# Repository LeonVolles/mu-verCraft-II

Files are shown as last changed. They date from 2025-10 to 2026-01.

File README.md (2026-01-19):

# µ-verCraft II

In this project we develloped a micro autonomous hovercraft with WiFi control, PID-stabilized yaw control, and autonomous navigation capabilities.

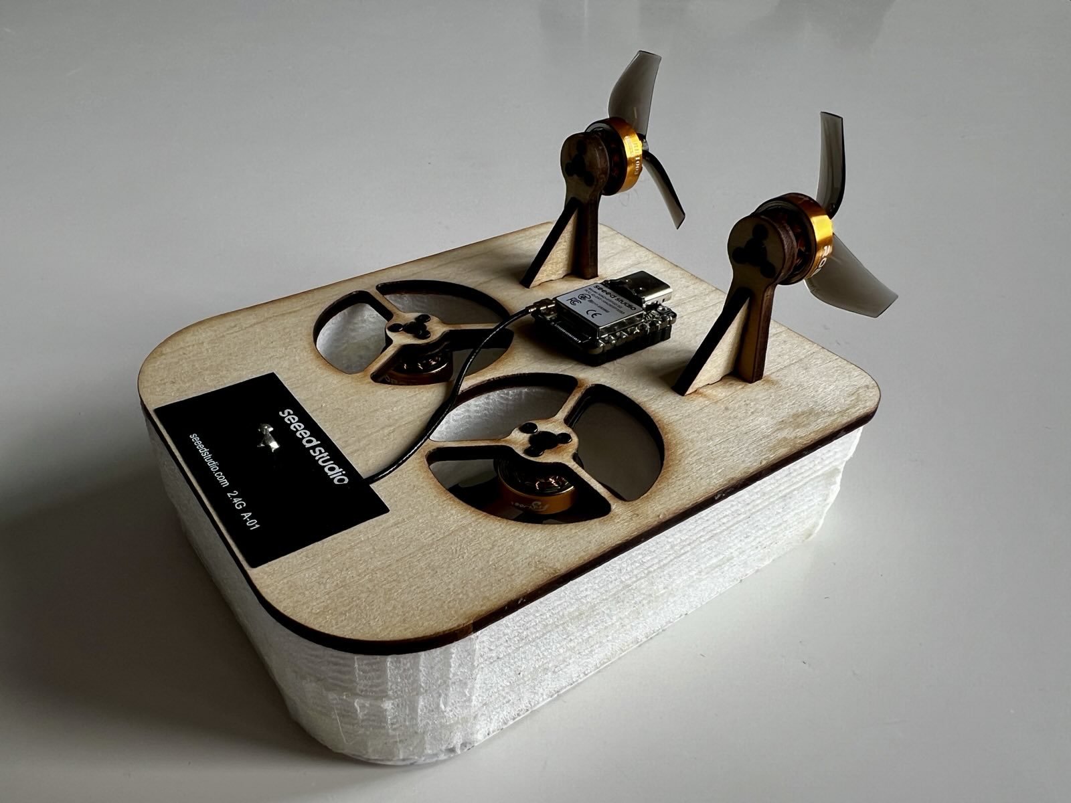
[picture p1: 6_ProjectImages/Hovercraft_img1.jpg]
µ-verCraft II hovercraft


## Overview

µ-verCraft II is an ESP32-S3-based hovercraft designed to navigate autonomously along a predefined track in the ENSMM hall. The system uses IR sensors for line detection, a 10-DOF IMU for orientation, and implements real-time control using FreeRTOS.

## Features

- **WiFi-based remote control** via web interface (no app required)
- **PID yaw-rate stabilization** using complementary filter and magnetometer
- **Autonomous navigation mode** with IR line detection and position correction
- **Real-time telemetry** (battery voltage, current, capacity estimation)
- **DShot ESC protocol** for brushless motor control

## Hardware

- ESP32-S3 microcontroller
- 10-DOF IMU (ADXL345, ITG3205, QMC5883, BMP280)
- 4x brushless motors with ESCs
- IR sensors for line tracking
- LiPo battery monitoring system

## CAD

- The CAD was created in Creo10 and is provided

## Getting Started

1. Clone the repository
2. Open in VS Code with PlatformIO extension
3. Calibrate magnetometer using provided protocol
4. Connect to WiFi AP and access web interface for control

## Project Structure

- `src/main.cpp` - Main entry point with FreeRTOS task setup
- `src/hovercraft_variables.*` - Global configuration and pin definitions
- Motor control, IMU, PID, battery monitoring, and WiFi modules

---

**ENSMM/Supmicrotech - Project PIST 2025/26 - Leon VOLLES & Luis GÖBES**

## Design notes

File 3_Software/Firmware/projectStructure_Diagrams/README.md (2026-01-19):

# Project Structure Diagrams

This folder contains scripts that generate architecture/project diagrams.

## Icon legend (local)

The generators use custom icons from `projectStructure_Diagrams/icons/`:
- `Hovercraft_variables.png` = configuration blocks
- `task.png` = RTOS tasks
- `data.png` = data/state/queues/globals
- `function.jpg` = functions/logic blocks
- `motor.png` = motors / propulsion

When none of these fit, the generators use `cpp.png` as a generic fallback icon.

## High-level code-structure diagrams

Generator:
- `generate_code_structure_high_level.py`

Outputs:
- `high_level_setup.png` (only: `main` creates RTOS tasks)
- `high_level_manual_piloting.png` (Web-App -> yaw PID + 10DOF/comp filter -> mixer -> motor ctrl -> DSHOT -> motors)

## Motor stack overview

Generates a first architecture overview for:
- `lib/motor_mixer`
- `lib/motor_ctrl`

### Prerequisites (Windows)

1. Python package:
   - `pip install diagrams`
2. Graphviz (required by `diagrams`):
   - `winget install Graphviz.Graphviz`
   - or `choco install graphviz`

Make sure the Graphviz `dot` executable is available on your `PATH` (open a new terminal after installing).

### Generate

From the firmware root:

```powershell
python .\projectStructure_Diagrams\generate_motor_architecture.py
```

Output:
- `projectStructure_Diagrams/motor_architecture.png`

## Manual mode overview (growing)

Generates a conceptual diagram for the current manual-mode chain:

### Generate

From the firmware root:

```powershell
python .\projectStructure_Diagrams\generate_manual_mode_architecture.py
```

Output:

This script also generates clearly labeled sub-diagrams (to keep the overview readable):

## Autonomous mode (M-Mode) diagrams

Generates diagrams for autonomous mode (the website “M” button), centered around:
- `lib/autonomous_sequence`

### Generate

From the firmware root:

```powershell
python .\projectStructure_Diagrams\generate_autonomous_mode_architecture.py
```

Output:
- `projectStructure_Diagrams/autonomous_mode_architecture.png`
- `projectStructure_Diagrams/autonomous_mode_sequence_core.png`

### Optional: custom output directory

```powershell
python .\projectStructure_Diagrams\generate_motor_architecture.py .\projectStructure_Diagrams
```

Or via env var:

```powershell
$env:DIAGRAM_OUT_DIR = ".\\projectStructure_Diagrams"
python .\projectStructure_Diagrams\generate_motor_architecture.py
```

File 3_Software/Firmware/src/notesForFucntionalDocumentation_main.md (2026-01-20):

<!-- Note, it is intentionnal that the first heading starts as a "level2"/## and not as level1/# and should be kept like this!! -->
## main (application entry point)

### Main idea
This file is the integration point of the whole firmware: it wires together all subsystems (motors, mixer, IMU, WiFi/web control, sensors, battery) and starts the FreeRTOS tasks that make the hovercraft run.

### Where it is used / how it is called
- This is the Arduino entry point compiled by PlatformIO: [src/main.cpp](src/main.cpp).
- `setup()` runs once after boot, then FreeRTOS tasks execute continuously; `loop()` is intentionally unused.

### Project structure: what runs when

#### Boot sequence (high level)
1. **Boot → `setup()`**: initialize peripherals, create the control queue, start WiFi + web control, then create RTOS tasks.
2. **Runtime**: tasks run concurrently on the ESP32’s two cores.
3. **Safety default**: motors start disarmed (`motorsEnabled=false`) and the motor task keeps outputs safe until arming is received.

#### Data flow overview (who talks to whom)
- **Web UI → NetworkPiloting callbacks → control queue**
	- WebSocket messages update `g_latestSetpoints` and immediately publish them using `xQueueOverwrite(g_controlQueue, ...)`.
	- The queue length is 1, so the motor task always consumes the **latest** setpoints.
- **IMU task → shared yaw-rate → motor task**
	- IMU task updates `g_yawRateMeasured_dps` and `g_lastYawRateUpdate_us`.
	- Motor task checks “freshness” (timestamp age) before using yaw-rate for control.
- **Motor task → mixer → motor controller → ESCs**
	- Motor task computes the yaw-rate control command (`diffCmd`) via `PIDController`.
	- `MotorMixer` converts lift/thrust/diff into 4 motor percentages.
	- `MotorCtrl` sends DShot commands to the ESCs.
- **Battery task → shared telemetry → `/debug`**
	- Battery task updates shared telemetry values (voltage/current/mAh).
	- The web UI reads telemetry/state via HTTP polling of `/debug`.

#### Task map (what each task does)
The firmware creates multiple tasks in `setup()` using `xTaskCreatePinnedToCore(...)`.

##### task_wifiManager (core 0)
- Purpose: lightweight periodic diagnostics (heap/stack prints).
- Note: the async server handles network I/O callbacks in its own context; telemetry/state for the UI is served via `/debug`.

##### task_imu (core 1)
- Initializes IMU, then runs a periodic loop at **200 Hz** (`vTaskDelayUntil(..., 5ms)`).
- Reads gyro continuously; reads magnetometer slower (~20 Hz) and updates yaw complementary filter.
- Publishes yaw rate (deg/s) to the shared variables for the control loop.

**Heading sign / offset note:** the heading published to the UI and heading-hold (`g_yawMeasured_deg`) is a **mounting-corrected** magnetometer+gyro estimate. The IMU applies a hardcoded transform `heading_corrected = wrap360(180 - heading_raw)` so the displayed heading has the desired 180° offset and increases in the chosen positive rotation direction.

If you later enable a non-zero heading-controller `Kd`, ensure the yaw-rate signal used for derivative-on-measurement has the **same sign convention** as the heading (positive yaw-rate means heading increasing).

##### task_motorManagement (core 1)
- Runs the main control loop at `global_ControlLoopRate_Hz` using `vTaskDelayUntil`.
- Non-blocking reads of `g_controlQueue` to get the latest setpoints.
- Implements yaw-rate control:
	- Converts steering percent to yaw-rate setpoint using `global_MaxYawRateSetpoint_dps`.
	- If motors are armed and gyro data is fresh: `PIDController.update(...)` → `diffCmd`.
	- Otherwise: PID reset + `diffCmd = 0`.
- Applies safety gates:
	- Always calls `motorCtrl.setMotorsEnabled(mySetPoint.motorsEnabled)`.
	- If disarmed, forces thrust and diff to zero; lift can be “latched” but not applied until arming.
	- If lift is disabled, calls `motorCtrl.applyLiftOff()` and forces mixer lift to 0.

##### task_irSensors (core 1)
- Polls for ISR-completed measurements (`irSensors.hasNewMeasurement()`) and consumes them.
- Currently prints debug values (angle to line, lateral velocity). Intended as a future navigation input.
- Typical polling delay is ~20ms.

##### task_batteryMonitor (core 1)
- Calls `batteryMonitor.update()` and prints voltage/current/mAh.
- Updates shared telemetry state used by `/debug`.

##### task_blink (core 1)
- Simple LED blink for testing.

### Functionalities implemented (project-level)
- **System bring-up**: initialize motor outputs, mixer state, sensor interrupts, battery ADC scaling, WiFi AP, and web control.
- **Real-time scheduling**: run IMU acquisition and control loop periodically with `vTaskDelayUntil`.
- **Command & telemetry plumbing**:
	- WebSocket commands → queue → control loop.
	- Telemetry/state → `/debug` JSON (polled by the web UI).
- **Core separation**: keep network housekeeping on core 0; keep control/sensing on core 1.
- **Safety behaviors**: disarm defaults, lift-off handling, PID reset on stale sensor data.

### Methods / functions overview
This file is mostly glue code and task entry points (not a class).

- `setup()`
	- Initializes serial + LED, motors (`motorCtrl.init(...)`), mixer (`motorMixer.init()`), IR sensors (`irSensors.begin()`), battery monitor (`batteryMonitor.init(...)`).
	- Creates the control queue (`g_controlQueue = xQueueCreate(1, sizeof(ControlSetpoints))`).
	- Starts WiFi AP and registers NetworkPiloting callbacks (lift/thrust/steering/arm).
	- Calls `networkPiloting.begin()` and creates RTOS tasks.

- `loop()`
	- Empty by design (everything runs in tasks).

- Task functions (`task_wifiManager`, `task_imu`, `task_motorManagement`, `task_irSensors`, `task_batteryMonitor`, `task_blink`)
	- Each is an infinite loop; timing is controlled by `vTaskDelay(...)` or `vTaskDelayUntil(...)`.

### Parameters used (configuration & tuning)
Most parameters come from [src/hovercraft_variables.h](src/hovercraft_variables.h) (with definitions in [src/hovercraft_variables.cpp](src/hovercraft_variables.cpp)). Key groups:

- **Motor hardware & safety**: `global_PIN_MOTOR_*`, `global_MotorsReversed*`, `global_AllMotorsScalePercent`.
- **Control loop**: `global_ControlLoopRate_Hz`, `global_MaxYawRateSetpoint_dps`.
- **Yaw-rate PID**: `global_YawRatePid_Kp`, `global_YawRatePid_Ki`, `global_YawRatePid_Kd`, `global_YawRatePid_OutputLimit`, `global_YawRatePid_IntegratorLimit`.
- **IMU filter**: `global_ComplementaryFilter_yawAlpha`.
- **Web control scaling**: `global_WebThrustPresetPercent`.
- **WiFi**: `global_WifiApSsid`, `global_WifiApPassword`.
- **IR sensors**: `global_PIN_IR_SENSOR_*`, `global_IRSensorDistance_a_meters`.
- **Battery monitor**: `global_PIN_BATTERY_*`, `global_BatteryVoltage_VoltageDividerRatio`, `global_BatteryCurrent_VoltageDividerRatio`, `global_BatteryCurrent_SensorScaler_AmpsPerVolt`.

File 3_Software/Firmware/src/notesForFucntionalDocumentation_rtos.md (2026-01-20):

<!-- Note, it is intentionnal that the first heading starts as a "level2"/## and not as level1/# and should be kept like this!! -->
## RTOS (FreeRTOS on ESP32)

### For people that are new to multi-threading
An RTOS lets you split one big `loop()` into multiple independent “tasks” that run *as if* they were in parallel. The RTOS decides which task runs when, so timing-critical work (e.g. control loops) can keep a stable update rate even while other work (e.g. networking) is happening.

### Main idea
This firmware uses FreeRTOS to run multiple subsystems concurrently (IMU, control loop, sensors, diagnostics) with explicit timing and priorities.

Networking is implemented using an async web stack (AsyncTCP/ESPAsyncWebServer). Its callbacks run in their own context, so the project does not need a dedicated “networking loop task” for basic operation.

### What an RTOS is (and why we use it)
FreeRTOS is a small real-time operating system used on microcontrollers. “Real-time” here means we care about predictable timing: a task can run periodically (e.g. every 5ms) and the scheduler helps keep that periodic behavior even when other tasks are active.

Official FreeRTOS website: https://www.freertos.org/

### Two cores on the ESP32 (what that means)
Many ESP32 chips have two CPU cores. In practice that means the RTOS can run one task on core 0 while another task runs on core 1 at the same time.

In this firmware we *pin* some tasks to a specific core using `xTaskCreatePinnedToCore(...)`:
- **Core pinning** is mainly used to isolate “noisy” workloads (like network/web housekeeping) from timing-sensitive workloads (like sensor reading / control loops).
- Pinning does not magically make code thread-safe: any data shared between tasks still needs safe handoff (queues, atomic variables, etc.).

### Scheduling (very short reminder)
The scheduler is the RTOS component that decides which task runs next based on priority and “readiness”. A task becomes not-ready when it blocks (e.g. delays for some time, waits on a queue), and ready again when that wait condition is satisfied.

Common timing patterns you’ll see in this firmware:
- `vTaskDelay(...)`: simple “sleep” for at least a given time.
- `vTaskDelayUntil(...)`: periodic scheduling pattern (tries to keep a constant period, useful for control loops).

### RTOS building blocks used in this project (high level)
- **Tasks:** each subsystem runs in its own task function.
- **Priorities:** tasks can be assigned different priorities so time-critical tasks run first.
- **Queues:** tasks exchange data without sharing raw variables directly (producer/consumer pattern).

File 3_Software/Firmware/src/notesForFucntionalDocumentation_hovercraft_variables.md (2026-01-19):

<!-- Note, it is intentionnal that the first heading starts as a "level2"/## and not as level1/# and should be kept like this!! -->
## hovercraft_variables (global project settings)

### Main idea
This file is the single place to tune the hovercraft: pin assignments, control loop tuning, and user-facing presets are centralized here so you don’t have to hunt through every subsystem.

### Where it is used / how it is called
- Declarations live in [src/hovercraft_variables.h](src/hovercraft_variables.h) and the actual values are defined in [src/hovercraft_variables.cpp](src/hovercraft_variables.cpp).
- Almost every subsystem consumes these values indirectly, but the main wiring is done in [src/main.cpp](src/main.cpp) when objects are constructed and initialized.

### Define all IO-Pins 
These constants define how the ESP32 is wired to the hardware. If the wiring changes, change values here.

- `LED_PIN` (int)
	- Onboard status LED used by the blink test task in [src/main.cpp](src/main.cpp).
	- Default is `LED_BUILTIN`.

- `global_PIN_MOTOR_FL`, `global_PIN_MOTOR_FR`, `global_PIN_MOTOR_BL`, `global_PIN_MOTOR_BR` (gpio_num_t)
	- DShot/ESC signal pins for the 4 motors (Front-Left, Front-Right, Back-Left, Back-Right).
	- Used in `motorCtrl.init(...)` in [src/main.cpp](src/main.cpp).

- `global_PIN_BATTERY_VOLTAGE_MONITOR`, `global_PIN_BATTERY_CURRENT_MONITOR` (gpio_num_t)
	- ADC pins for battery voltage and current sensing.
	- Passed to `batteryMonitor.init(...)` in [src/main.cpp](src/main.cpp).

- `global_PIN_IR_SENSOR_FL`, `global_PIN_IR_SENSOR_FR`, `global_PIN_IR_SENSOR_BM` (gpio_num_t)
	- ADC pins for the 3 IR line sensors (Front-Left, Front-Right, Back-Middle).
	- Sampled via `analogRead(...)` in `task_irSensors` in [src/main.cpp](src/main.cpp) (mapping/order: index0=BM, index1=FL, index2=FR).
	- Passed into the `IRSensors` constructor; `IRSensors::begin()` currently creates the internal sample queue used between the sampling and processing tasks.

- `global_PIN_I2C_SDA`, `global_PIN_I2C_SCL` (gpio_num_t)
	- Intended I2C pin definitions for sensors.
	- Note: the current IMU implementation starts I2C via `Wire.begin((int)SDA_PIN,(int)SCL_PIN)` if the macros `SDA_PIN`/`SCL_PIN` are defined, otherwise it calls `Wire.begin()` defaults (see [lib/imu/src/imu.cpp](lib/imu/src/imu.cpp)). These globals are currently not referenced directly.

### Battery related limits and variables 
These constants configure how ADC readings are converted into real battery voltage/current, plus optional low-voltage thresholds.

- `global_BatteryVoltage_VoltageDividerRatio` (float)
	- Divider ratio used to reconstruct battery voltage from the ADC pin voltage.
	- The battery monitor computes: $V_{batt} = V_{pin} / ratio$ (see [lib/battery_monitor/src/battery_monitor.cpp](lib/battery_monitor/src/battery_monitor.cpp)).
	- For a simple resistor divider, a typical ratio is $ratio = R_{bottom} / (R_{top}+R_{bottom})$.

- `global_BatteryCurrent_VoltageDividerRatio` (float)
	- Scaling factor applied to the measured current-sense pin voltage.
	- The battery monitor computes `sensor_mV = iPin_mV * ratio`.
	- Keep at `1.0` if you have no divider/scaler on the current sense line.

- `global_BatteryCurrent_SensorScaler_AmpsPerVolt` (float)
	- Betaflight-style current scale, **in units of [0.1 mV]/A** (despite the variable name).
	- The battery monitor converts it to mV/A via `mvPerAmp = scale * 0.1` and computes $I(A)=sensor_{mV}/(mV/A)$.
	- Example: `130` means 13 mV/A.

- `global_BatteryVoltageLow_WarningLow` (float, Volts)
	- Intended warning threshold for low battery.
	- Note: currently not enforced automatically; battery voltage is mainly sent as telemetry (see the battery task in [src/main.cpp](src/main.cpp)).

- `global_BatteryVoltageLow_MotorCutoffLow` (float, Volts)
	- Intended hard cutoff threshold where motors should stop.
	- Note: currently not enforced automatically; you can implement a failsafe in the motor task or battery task based on this.

### Motor control variables 
These variables define motor output scaling and direction conventions.

- `global_AllMotorsScalePercent` (float, %)
	- Global power cap applied inside `MotorCtrl` to reduce maximum throttle.
	- Used when `MotorCtrl motorCtrl(global_AllMotorsScalePercent)` is constructed in [src/main.cpp](src/main.cpp).

- `global_NegativeRpmScaleFactor` (float)
	- Reverse-direction compensation factor.
	- Applied only when a motor command is negative, to boost reverse output if reverse thrust is weaker (used in [lib/motor_ctrl/src/motor_ctrl.cpp](lib/motor_ctrl/src/motor_ctrl.cpp)).

- `global_MotorsReversedFL`, `global_MotorsReversedFR`, `global_MotorsReversedBL`, `global_MotorsReversedBR` (bool)
	- Per-motor direction flags.
	- Passed into `motorCtrl.init(...)` in [src/main.cpp](src/main.cpp) so that “positive thrust” matches the physical direction of the mounted propellers.
	- These are non-`const` globals, but in the current firmware they are effectively “startup configuration”.

### Web piloting / UI presets 
These values define what the web UI offers (presets) and how user input is interpreted.

- `global_WebLiftPresetPercent_Array[]` (float array, %)
	- List of lift presets shown/cycled in the web UI.
	- Used by the web UI generation logic in [lib/network_piloting/src/network_piloting.cpp](lib/network_piloting/src/network_piloting.cpp).

- `global_WebLiftPresetPercent_Array_len` (size_t)
	- Length of the lift preset array.
	- Used to bound preset iteration in [lib/network_piloting/src/network_piloting.cpp](lib/network_piloting/src/network_piloting.cpp).

- `global_WebLiftPresetPercent_Array_startIndex` (int)
	- Which preset becomes the first “non-zero” selection after startup (startup selection is always 0).
	- Used by preset cycling logic in [lib/network_piloting/src/network_piloting.cpp](lib/network_piloting/src/network_piloting.cpp).

- `global_WebThrustPresetPercent` (float, %)
	- Scales the maximum thrust command coming from the web UI.
	- Implemented in the thrust callback in [src/main.cpp](src/main.cpp): `scaled = thrustPercent * (preset/100)`.

### Wifi SSID, PW, IP addresses 
These parameters configure the ESP32 SoftAP and the webserver port.

- `global_WifiApSsid` (char[])
	- SSID (network name) for the ESP32 Access Point.
	- Used in `wifiManager.startAccessPoint(...)` in [src/main.cpp](src/main.cpp).

- `global_WifiApPassword` (char[])
	- WPA2 password for the Access Point (must be at least 8 characters).
	- Used in `wifiManager.startAccessPoint(...)` in [src/main.cpp](src/main.cpp).

- `global_WebServerPort` (uint16_t)
	- TCP port for the embedded webserver (typically 80).
	- Used to construct the webserver inside `NetworkPiloting` (see [lib/network_piloting/src/network_piloting.cpp](lib/network_piloting/src/network_piloting.cpp)).

### Gyro/IMU/Complementary filter settings 
These values tune the IMU yaw estimation.

- `global_ComplementaryFilter_yawAlpha` (float, unitless)
	- Complementary filter weight for yaw: higher means “trust gyro more, correct slowly with magnetometer”.
	- Used when constructing the IMU and when configuring the filter in the IMU task in [src/main.cpp](src/main.cpp).
	- Typical range is 0…1.

### Control loop constants 
These define timing of the main control loop.

- `global_ControlLoopRate_Hz` (float, Hz)
	- Target frequency of the motor/control task loop.
	- Used to compute the periodic delay in `task_motorManagement` in [src/main.cpp](src/main.cpp).

### PID controller constants 
Yaw-rate control tuning parameters.

- `global_YawRatePid_Kp`, `global_YawRatePid_Ki`, `global_YawRatePid_Kd` (float)
	- Gains for the yaw-rate PID controller.
	- Used to initialize `yawRatePid` in `task_motorManagement` in [src/main.cpp](src/main.cpp).

- `global_YawRatePid_OutputLimit` (float)
	- Output clamp for the PID command (expected mixer units are roughly -100…100).

- `global_YawRatePid_IntegratorLimit` (float)
	- Integrator clamp (anti-windup) in the same units as the PID output.

- `global_MaxYawRateSetpoint_dps` (float, deg/s)
	- Maps full steering input (±100%) to a yaw-rate setpoint.
	- Used in [src/main.cpp](src/main.cpp) to compute the yaw-rate setpoint from the user steering slider.

- `global_YawCenterSensitivity` (float, deg/s)
	- “Center sensitivity” for the yaw command curve: sets how responsive yaw feels for *small* steering deflections.
	- Interpreted as the approximate slope around stick/slider center (0%).
	- Used in [src/main.cpp](src/main.cpp) to shape the mapping from steering percent to yaw-rate setpoint.

- `global_YawRateExpo` (float, unitless, 0…1)
	- “Expo” shaping for the yaw command curve: higher expo makes the response softer around center and ramps up more strongly towards full deflection.
	- Used together with `global_YawCenterSensitivity` and `global_MaxYawRateSetpoint_dps` to compute the yaw-rate setpoint from the user steering slider.
	- Used in [src/main.cpp](src/main.cpp) in the yaw setpoint mapping.
	- **Visualization tool:** there is a curve visualizer at `3_Software/rates.html` (open it in a browser) to inspect the response curve.

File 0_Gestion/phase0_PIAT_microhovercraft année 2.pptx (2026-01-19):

## Projet micro hovercraft

ENSMM / Option SMR

## Objectif long terme (3-4 ans)

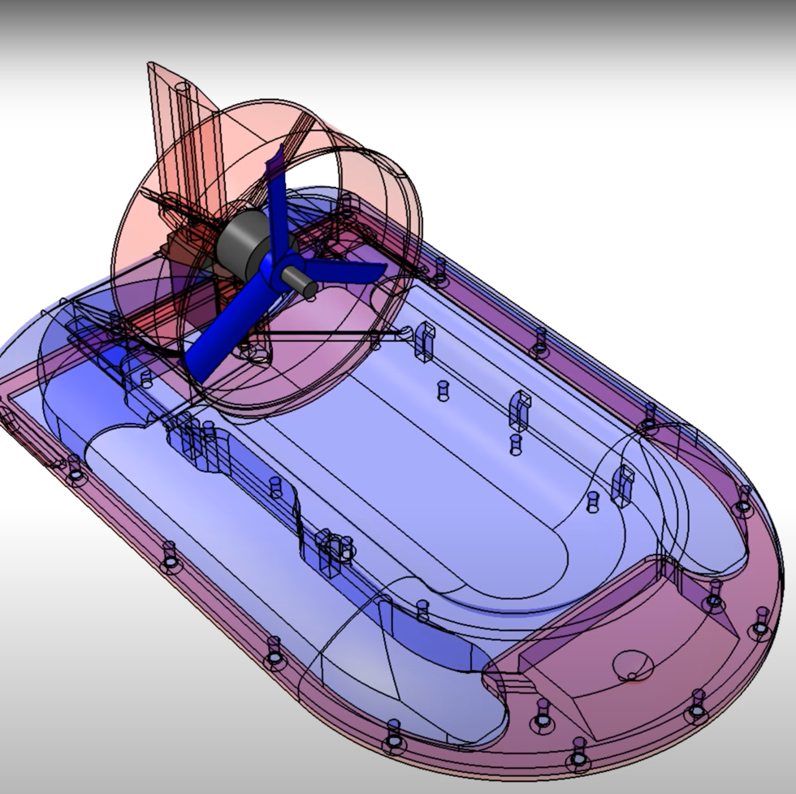
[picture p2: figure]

Course de 2+ micro hovercrafts autonomes dans le hall de l’ensmm

Dimensions caractéristiques des hovercrafts :
entre 10 et 30 cm

## Le circuit

Bandes blanches au sol pour une relocalisation ”alternée” en x et en y

Recalage en y et θ

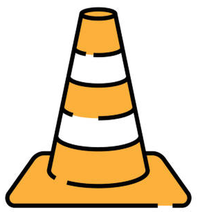
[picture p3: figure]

Recalage en y et θ

Micro hovercrafts qui doivent tourner autour de 2 balises

Recalage en y et θ

y

Recalage en x et θ

x

## Les capteurs embarqués

Extéroceptifs : 2+ capteurs de présence de bande blanche sur le sol
Proprioceptif : centrale inertielle MEMS

La position des bandes blanches étant connue, leur détection par l’hovercraft doit permettre de recaler son angle θ ainsi qu’une des deux composantes x, y qui sont calculés avec la centrale inertielle.
Intérêt : compensation des dérives temporelles induites par l’IMU et calcul de localisations critiques lors du contournement des balises.

## Objectifs année 2 pour une équipe de 2+ étudiants

Du plus prioritaire au moins prioritaire :
1) Conception puis fabrication de la v2 du micro hovercraft sur la base du REX établit par la précédente équipe.
2) Mise au point du module de localisation de l’hovercraft (hardware et softwave) et validation en mode téléopéré (liaison bluetooth)
3) Elaboration d’une première stratégie de commande permettant de faire un tour de circuit en mode autonome.

## Le point de départ (v1)

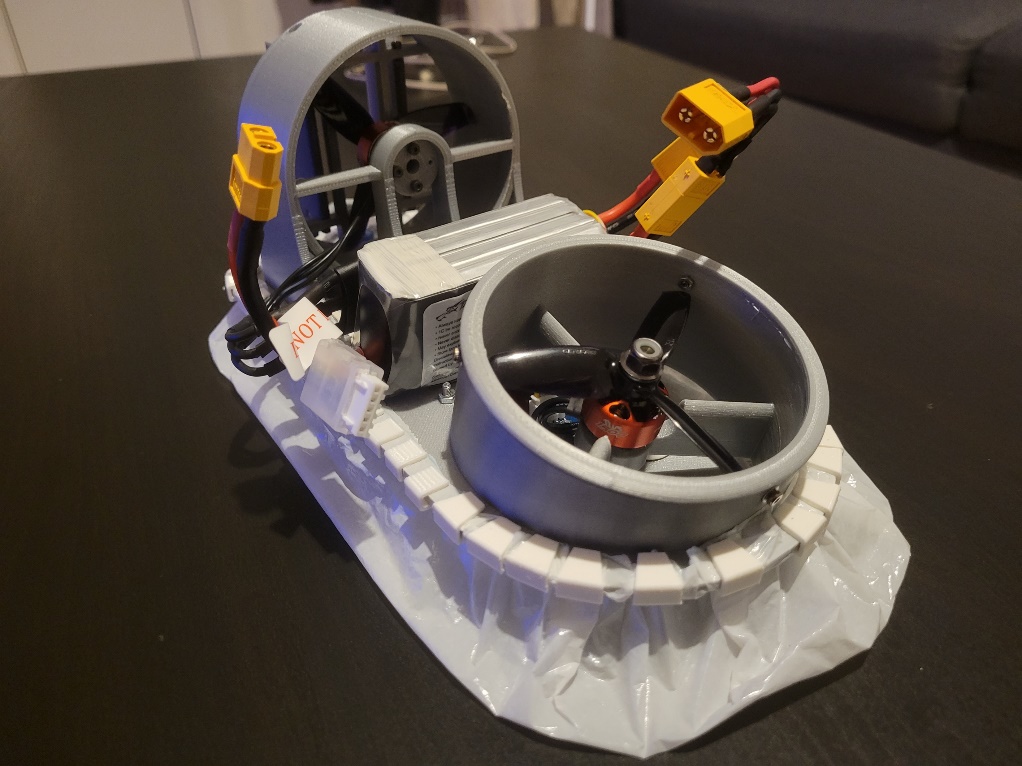
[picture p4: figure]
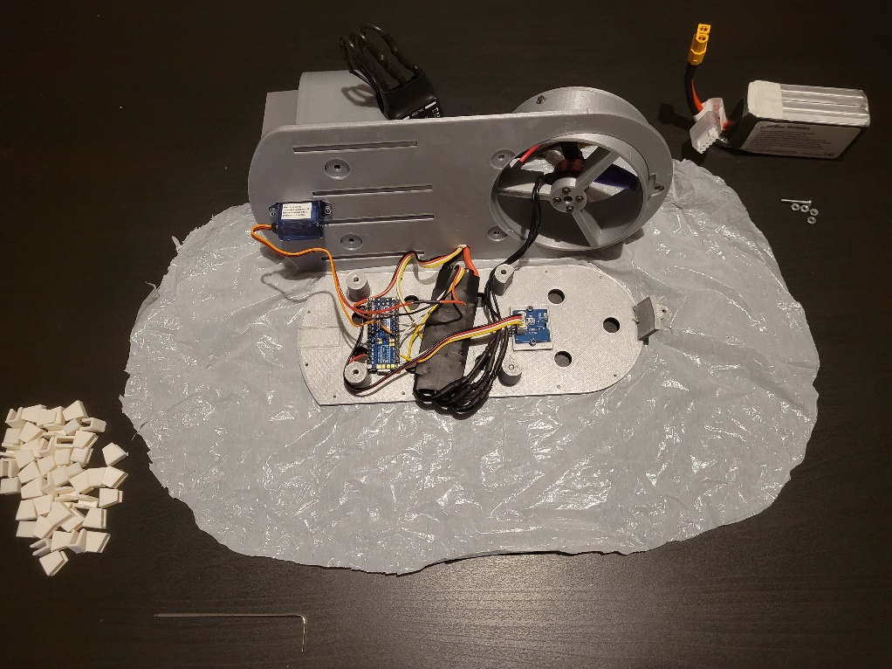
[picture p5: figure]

## Exemples de vidéos sous Youtube

FABRICATION d'un AÉROGLISSEUR TÉLÉCOMMANDÉ (Impression 3D, Assemblage et Test) (https://www.youtube.com/watch?v=NtjMhkQJuBA)
How I 3D Printed a FAST RC Hovercraft (https://www.youtube.com/watch?v=pHdO_BtYl7M)
Mini 3D (https://www.youtube.com/watch?v=mpqYlHTlXtA)Printed (https://www.youtube.com/watch?v=mpqYlHTlXtA) Hovercraft (https://www.youtube.com/watch?v=mpqYlHTlXtA)
Fully 3D printed hovercraft - build guide (https://www.youtube.com/watch?v=PtZ5-50kNHE)
How to make a mini hovercraft at home (https://www.youtube.com/watch?v=1OMSdA4-Gn4)
DIY Mini RC Hovercraft (https://www.youtube.com/watch?v=GS9JsYPLh7w)

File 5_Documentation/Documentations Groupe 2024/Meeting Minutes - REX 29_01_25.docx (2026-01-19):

# Meeting Minutes

Subject | Retour d’expérience pour la passation du projet PIST “Hovercraft”
Date | 29/01/25
Attendees | ENSMM : BARBAUT Christophe, BAUDRI Romuald, PIAT Emmanuel
Author | BAUDRI Romuald

Meeting Objectives/Discussion Points

Mettre en évidence les points à aborder pour le prochain groupe qui prendra ce projet.

- CAO
- Code
- AppInventor
- Liste d’item à acheter
- Liste documentation lien

Topic covered:

- Chargeur de batterie : Entrée 15V DC ; ampérage : 1.5/2.5A ; temps de charge 30 minutes.
- ServoMoteur : Faire attention lors de la manipulation, assez fragile mais fonctionnel.
- Hélices : Penser à des hélices symétrique pour le moteur de poussée
- ESC : Prendre des B-20 (présent sur le même site que précédent, voir dossier Hovercraft (google Sheet) cf.liste achat à la fin)
- Soudure à améliorer, la connexion entre ESC et Moteur.
- ATTENTION POUR LE MOTEUR DANS LE CODE DE CALIBRATION ET DE CONTROL DE NE JAMAIS LANCER UNE PUISSANCE SUPÉRIEUR À 1300µs.
  - Et avec les ESC B-20 le mapping du contrôle sera à refaire et la calibration.
  - TOUJOURS FAIRE ATTENTION A LA SURCHAUFFE DU MOTEUR ET DES CÂBLES
- Batteries : Penser à prendre plus léger, mais pas une priorité seulement à la fin
- Fragilité de la jupe : Matériaux à privilégier : ripstop nylon
- IMU : Pdf d’une thèse sur les IMU (pas simple)
- Vérifier et revoir le code pour le capteur IR, pas sur du fonctionnement.
- Application APP Inventor : https://appinventor.mit.edu/ voir cette outil en ligne (gratuit) uniquement Sur Android (IOS possible mais chiant)
  - Téléchargé sur le github dans le documents : Hovercraft/Code/HovercraftControlApp
  - Télécharger le fichier .aia et l’ouvrir dans l’application.

Lien :

  - https://github.com/RomualdBaudri/Hovercraft
  - https://drive.google.com/drive/folders/1frXN_9IN8mSaBTqvfHWEagb69dfuotS7?usp=sharing

Action Items

- Liste d’item à acheter :
  - PULSAR B-20 Régulateur de vitesse brushless de voiture (https://www.conrad.fr/fr/p/pichler-modellbau-pulsar-b-20-regulateur-de-vitesse-brushless-de-voiture-charge-admissible-max-30-a-3204130.html)
  - Batterie LiPo 650mAh (https://www.conrad.fr/fr/p/tattu-pack-de-batterie-lipo-14-8-v-650-mah-nombre-de-cellules-4-95-c-softcase-xt30-2316799.html) (pas prioritaire)
    - Avec connecteur XT30 (voir avec Mr.Marionnet)
  - Vis CHC M2x10mm, M2x8mm, M2x6mm, M2x4mm avec boulon et rondelle
    - Lien Misumi (https://fr.misumi-ec.com/vona2/mech_screw/M3301000000/) partenaire ENSMM qui a tout type de vis
  - Jeu de tournevis 7 pièces hexagonal (https://www.conrad.fr/fr/p/wiha-jeu-de-tournevis-7-pieces-hexagonal-2481770.html)
  - Servomoteur (https://www.conrad.fr/fr/p/reely-mini-servomoteur-analogique-materiau-entrainement-plastique-systeme-de-connecteur-jr-2148502.html) (On en a cassé un)
- Conseille :
  - revoir avec Pierre ROUX pour la conception des “Rudders” (gouvernaille)
  - Retourner l’hélice de propulsion car montée comme elle est, elle tourne à l'envers…
  - Au niveau de la CAO : Comme pour le capteur IR faire un support pour pour y mettre la carte arduino
  - Prendre du ripstop nylon comme matériau pour la jupe.
  - Lien vers un ensemble de tutorial pour MIT App inventor et l'utilisation du BLE (https://community.appinventor.mit.edu/t/ble-esp32-bluetooth-send-receive-arduino-ide-multitouch/1980/4) (Attention ce n’est pas la même carte donc il faut s’adapter un petit peu)

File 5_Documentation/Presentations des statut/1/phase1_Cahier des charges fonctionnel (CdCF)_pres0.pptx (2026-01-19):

## Projet µ-verCraft

ENSMM / Option SMR

## Préparation

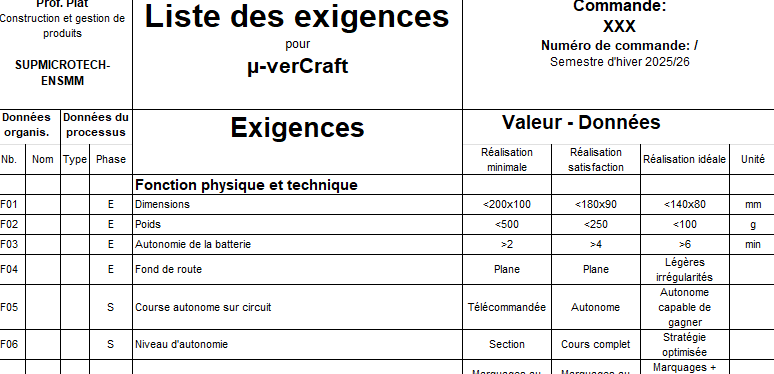
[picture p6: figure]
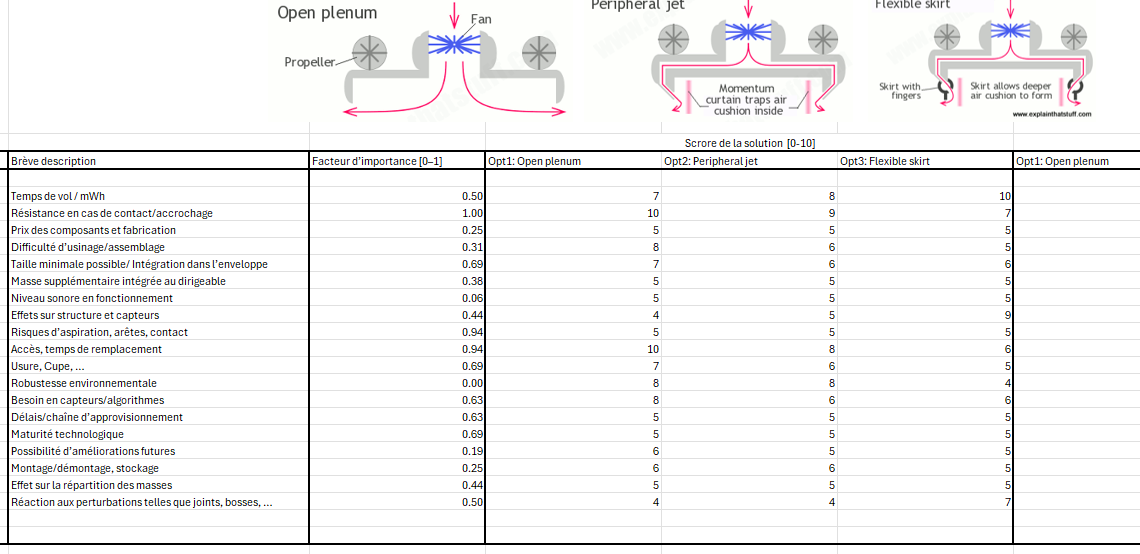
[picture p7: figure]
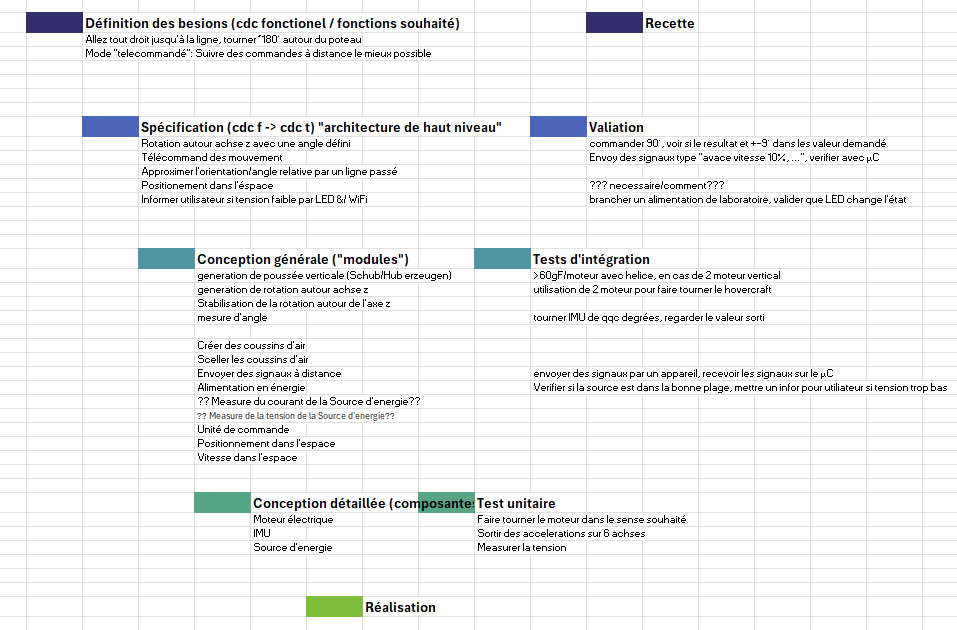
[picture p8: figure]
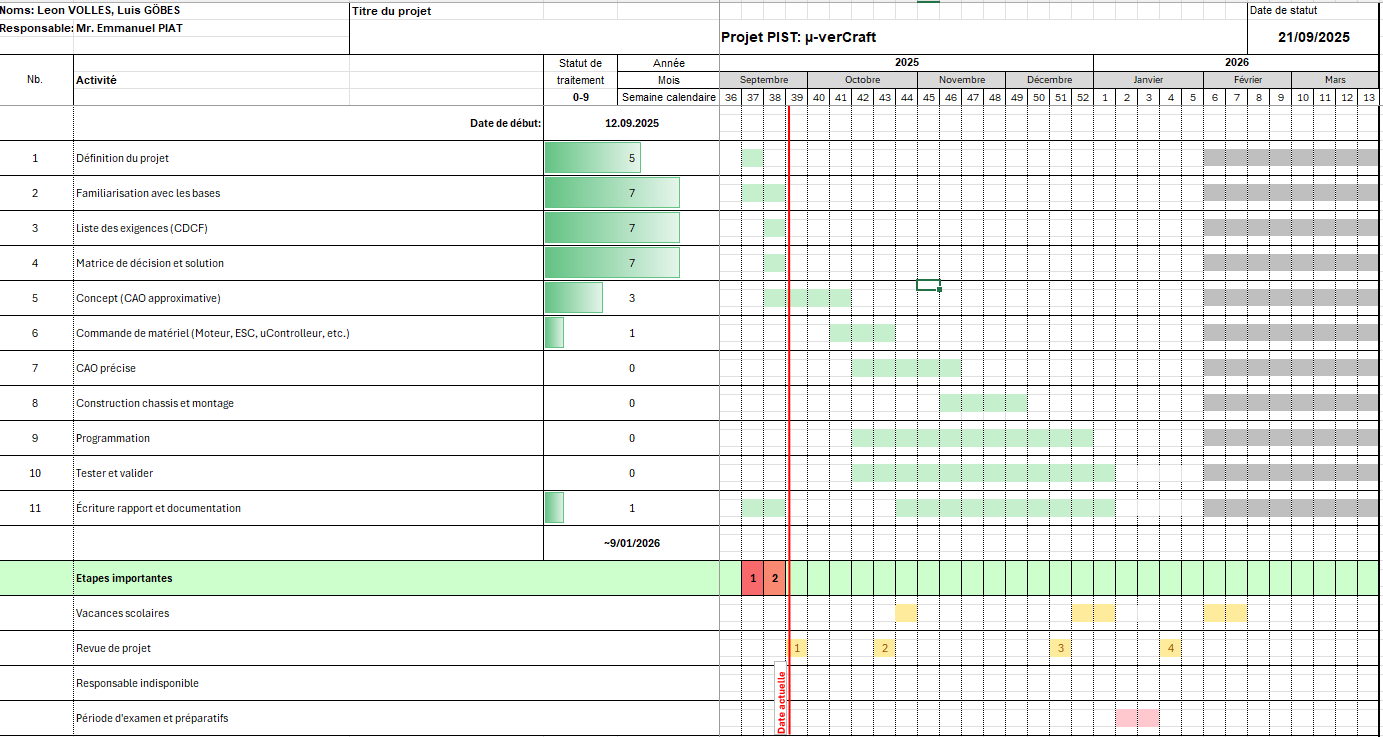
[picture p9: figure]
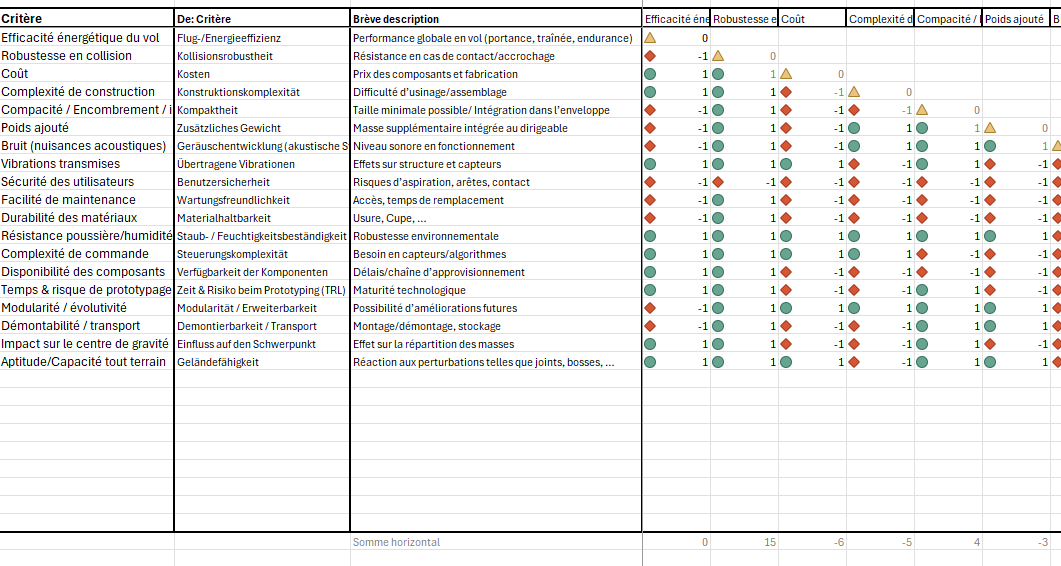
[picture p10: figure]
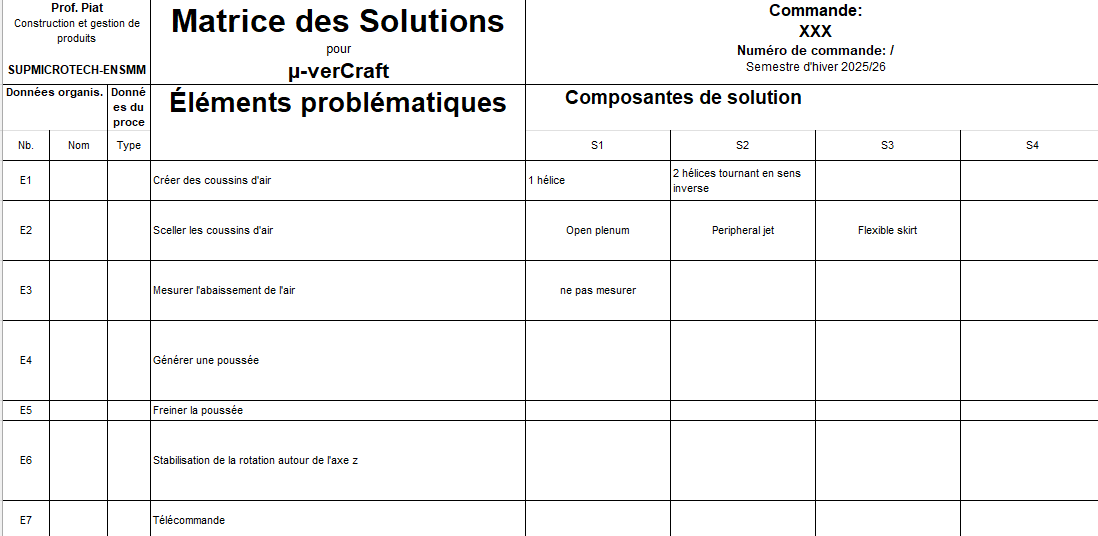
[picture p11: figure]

## Des questions

- Détection coord. x:
  - Y a-t-il une bande ?
  - Y a-t-il des rayons/ lignes diagonales en plus ?
- Quoi définit Recette?

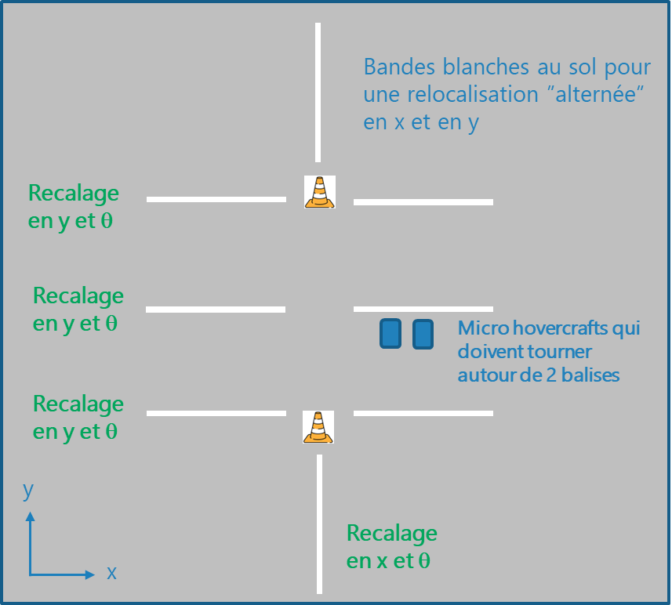
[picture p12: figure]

## Notre proposition

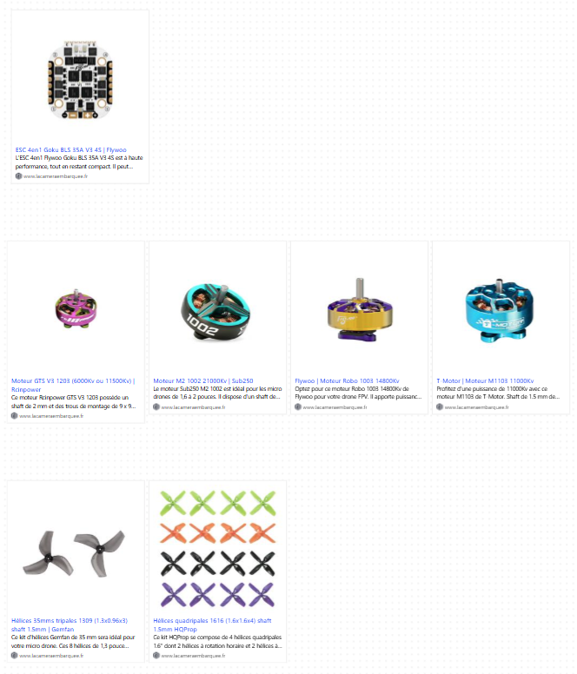
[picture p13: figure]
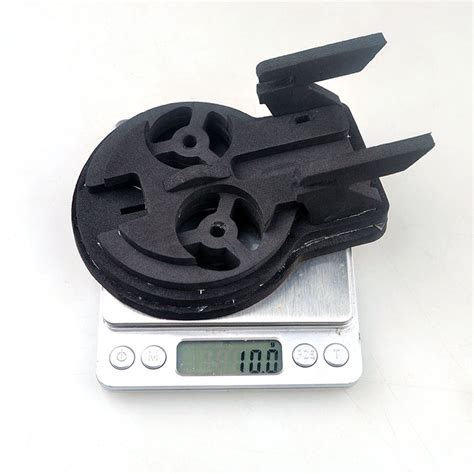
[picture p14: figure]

## Remarques

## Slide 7

- - Absegnen vom Zeitplan -> klar machen, dass wir zeitlich eher bald eine erste Bestellung für die Elektronik wollen (mitte Oktober wenn möglich (ESC, Motoren, Props, ESP, Akkus))- Absegnen vom typ des Hovercrafts (ob Schaumbasis ohne Schürzeauch recht ist) -> weil das einen großen Einfluss auf Design/komponentenwahl/größe hat- Absegnen vom CDC oder wie auch immer wir das nenne wollen=> Ziel gesamt: Dass wir theoretisch mit einem ersten CAD anfangen können=> Ziel, dass wir nächste Woche eine vollständige V-Modell-artige Grafik präsentieren könne, an die wir uns strikt halten, und NACH DER BENOTET WIRD (damit später kein „aber ich hätt das eigentlich doch lieber so“ rauskommt)

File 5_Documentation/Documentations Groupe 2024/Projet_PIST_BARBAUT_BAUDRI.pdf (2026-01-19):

## Documentation du Projet Hovercraft

BARBAUT Christophe

BAUDRI Romuald

3

ème Année Option SMR

January 20, 2025

Abstract

Ce document présente les étapes de conception, les défis techniques et les résultats obtenus dans le cadre du projet Hovercraft. En utilisant une carte Arduino Nano 33 BLE Rev2, une centrale inertielle (IMU), ce projet vise à démontrer la faisabilité d’un suivi précis de position dans un contexte de navigation autonome. Des suggestions d’améliorations et des ressources pour poursuivre le projet sont également proposées.

### Contents

Contents | 1
List of Figures | 2
1 Introduction (Christophe) | 3
2 Développement | 6
3 Axes d’Améliorations (Christophe/Romuald) | 22

3.1.1 | Optimisation de la Sustentation | 22
3.1.2 | Système de Propulsion | 22
3.2 Améliorations Électroniques | 22
3.2.1 | Gestion de l’Alimentation | 22
3.2.2 | Capteurs et Navigation | 22
3.3 Améliorations Logicielles | 22
3.3.1 | Application Mobile | 22
3.3.2 | Firmware Arduino | 22
3.4 Améliorations des Performances | 23
3.4.1 | Navigation Autonome | 23
3.4.2 | Contrôle et Stabilité | 23
3.5 Maintenance | 23
3.5.1 | Facilité de Maintenance | 23
4 Conclusion | 24
4.1 Rappel des objectifs et innovation | 24
4.2 Rétrospective sur le CDCF | 24
4.3 Retour sur le développement | 24
4.4 Impact du projet et perspectives | 24
4.5 Conclusion générale | 25
A Bibliographie/Netographie | 26
B Lien Github du Projet | 26
C Documentations Associées | 26

### List of Figures

1 | Diagramme Fast du projet | | 3
2 | Diagramme PERT | | 4
3 | Miniature de la 1ère vidéo | | 6
4 | Miniature de la 2ème vidéo | | 6
5 | Miniature de la 3ème vidéo | | 7
6 | Version 0.1 de l’hovercraft | | 8
7 | Version 0.4 de l’hovercraft, vue 1 | | 8
8 | Version 0.4 de l’hovercraft, vue 1 | | 8
9 | Image du clip pour la fixation de la jupe | | 9
10 | Résultat du prototypage | | 9
11 | Tableau présentant l’ensemble des paramètres programmable | 12
12 | Code pour la première version de l’application | 17
13 | Première version de l’application | 18
14 | Start Menu | 19
15 | Contrôle Manuelle | 19
16 | Start Menu 3rd Version | 20
17 | Manual 3rd Version | 20
18 | Image du circuit Sur l’arduino utilisé | 21

### 1 Introduction (Christophe)

Il est important de rapeller qu’initialement le projet était prévue pour 4 personnes. Nous avons pris le risque de le faire à 2 et nous somme satisfait de nos résulats actuel.

### 1.1 Objectifs

- Conception et réalisation d’un hovercraft autonome :

– Développement d’un système de sustentation efficace

– Implémentation d’un système de propulsion contrôlable

– Intégration d’un système de direction précis

- Mise en place d’un système de contrôle intelligent :

– Développement d’une interface de contrôle sans fil via Bluetooth (BLE)

– Implémentation de systèmes de sécurité pour les moteurs
– Gestion des différents modes de fonctionnement (manuel/autonome)
- Développement des capacités autonomes (très primitif) :

– Intégration d’un système de détection de ligne par capteur IR

– Mise en place d’un compteur de tours pour le suivi de parcours

- Optimisation des performances :

– Calibration précise des ESC pour un contrôle optimal

– Ajustement des paramètres de sustentation pour une efficacité maximale

– Développement d’un contrôle progressif pour la stabilité

### 1.2 Résumé des Étapes du Projet

On résume ici les différente étapes du projet, le matériel qui sera utilisé pour réponde au critères.

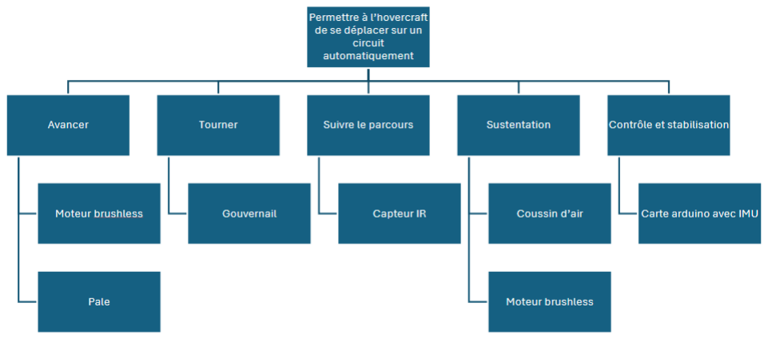
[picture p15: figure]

Figure 1: Diagramme Fast du projet

On peut résumé les étapes principale de ce projet dans ce diagramme PERT

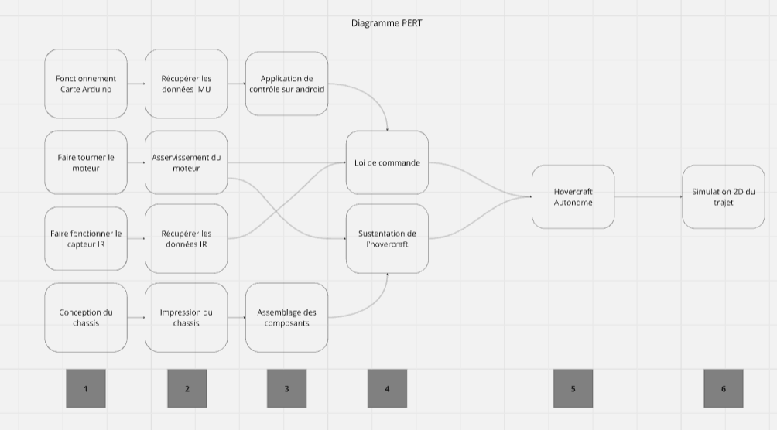
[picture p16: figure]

Figure 2: Diagramme PERT

### 1.3 Liste du Matériel

Nom | Nombre | Tr | Description | Commentaire
Moteur SmooX 1507 Plus - 3800KV | 4 | Validé | 3800KV | Fonctionne avec une batterie 4S
GEMFAN 3052 - Tri-pales - Polycarbonate | 2 | Validé | Shaft M5, diamètre 3 pouces | x4 par unit
ESCs (Régulateur brushless) | 4 | Validé | Pichler XQ - Charge admissible (max.): 50 A Continue 40 A
Servomoteur analogique | 2 | Validé | (L x l x H) 23 x 12 x 24 mm, Tension de fonc-tionnement 4.8 - 6 V
Arduino Nano 33 BLE Rev2 | 2 | Validé | Carte de développe-ment basée sur un mi-crocontrôleur Cortex-M4 avec Bluetooth 5 et IMU intégrée | Besoin d’un régula-teur de tension pour l’alimentation

Table 1: Liste du matériel pour le projet Hovercraft.

### 1.4 CDCF

Fonctions | Énoncé de la fonc-tion | Critères d’appréciation | Niveaux d’exigence
FP1 | Se déplacer de manière autonome | Précision des déplacements | < 5 cm d’erreur par rapport à la trajectoire cible
FP2 | Éviter les obstacles | Capacité à détecter et con-tourner les obstacles | Obstacle détecté à > 10 cm de distance
FP3 | Détecter une ligne noir au sol | Capacité à suivre les lignes et à se relocaliser | Distinguer une bande de 2 cm de largeur à une distance de 5 cm
FC1 | Être écologique | Consommation d’énergie ré-duite | Batterie rechargeable, durée de vie > 1 heure
FC2 | Coût de production abordable | Coût de fabrication par unité | < 250€
FC3 | Être esthétique | Design et finitions | Compact, design aéro-dynamique
FC4 | Respecter les normes de sécurité | Sécurité des composants et utilisateurs | Composants non coupants, tensions < 24V
FC5 | Facile à programmer et contrôler | Temps nécessaire à la config-uration | Moins de 30 minutes pour la configuration initiale
FC6 | Résister à l’usure et à l’humidité | Robustesse des matériaux | Matériaux imper-méables et résistants aux chocs
FC7 | Avoir une documenta-tion complète | Clarté des instructions et plans | Documentation tech-nique détaillée et schémas CAO fournis
FC8 | Installation faisable par des étudiants | Complexité des tâches | Niveau adapté pour des débutants en robotique et mécatronique
FC9 | Avoir un poids réduit | Maniabilité et transportabil-ité | P1 : Poids total < 750 g P2 : Poids total < 500g
FC10 | Loi de commande | Effectuer plusieurs simula-tion | Loi de commande cor-rect

Table 2: Cahier des charges fonctionnel du projet

### 2 Développement

### 2.1 Conception Assistée par Ordinateur (CAO) (Romuald)

La conception des pièces de l’hovercraft à été un des plus gros challenges de ce projet. La conception des pièces de l’hovercraft a été l’un des plus grands défis de ce projet.
Après une discussion avec M.PIAT, le responsable du projet, pour définir les objectifs, il était clair que nous ne voulions pas créer un simple mini hovercraft. Aujourd’hui, on trouve de nombreux projets similaires sur internet, mais ils ont tous un point commun : ils sont radiocommandés et mesurent en moyenne 30 cm de long. Notre défi principal était donc de concevoir un hovercraft encore plus compact (20 cm de long), tout en intégrant l’ensemble du système Arduino pour le rendre automatisé. À notre connaissance, une telle réalisation n’a jamais été faite auparavant.

### 2.1.1 Première étape : l’analyse

Ma première démarche a été d’analyser ce qui existait déjà, car je n’avais aucune expérience préalable dans ce domaine. Voici quelques exemples d’hovercraft qui m’ont inspiré :

1er exemple : Mini hovercraft RC imprimé en 3D (https://www.youtube.com/watch?v=mpqYlHTlXtA)
Ce modèle respectait nos objectifs en termes de dimensions, mais il ne permettait pas de réaliser du sur-place ni d’accueillir tous nos composants. À partir de cette analyse, j’ai décidé d’opter pour un système utilisant deux moteurs : l’un pour la propulsion et l’autre pour la sustentation.

Figure 3: Miniature de la 1ère vidéo

2ème exemple : Hovercraft RC avec système de sustentation innovant (https://www.youtube.com/watch?v=pHdO_BtYl7M)
Ce projet était intéressant et respectait la plupart de nos exigences. C’est pour cela que j’ai commencé ma première conception en CAO en m’en inspirant. Cependant, je me suis vite rendu compte qu’il n’était pas adapté. En particulier, cet hovercraft n’était pas assez modulable. De manière générale, ce projet était trop brouillon et ne me permettait pas de bien intégrer toutes nos contraintes.

Figure 4: Miniature de la 2ème vidéo

3ème exemple : Hovercraft RC modulaire (https://www.youtube.com/watch?v=rCYRUXrFhZc) et Améliorations du modèle (https://www.youtube.com/watch?v=FuvmvP_xeic)
C’est finalement sur la base de ce projet que j’ai conçu notre hovercraft. Ses principaux atouts étaient une CAO bien réalisée, un espace suffisant pour intégrer nos composants, et l’existence d’un forum actif autour de ce modèle, regroupant astuces, conseils et modifications. Le point négatif était sa taille : il était beaucoup trop grand. J’ai donc dû recréer toutes les pièces à partir de zéro pour respecter nos contraintes.

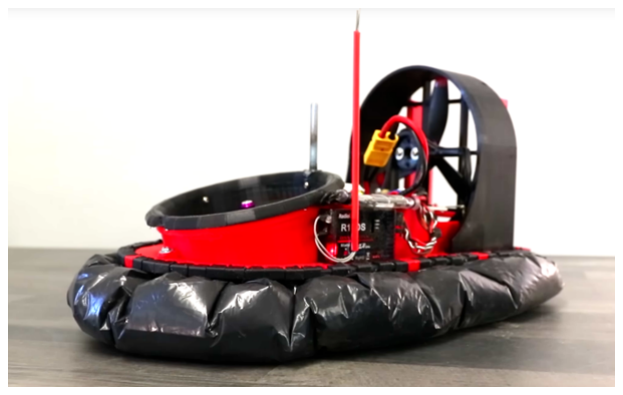
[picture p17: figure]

Figure 5: Miniature de la 3ème vidéo

### 2.1.2 Première version de l’hovercraft

Une fois chaque pièce réalisée individuellement, ce qui m’a pris le plus de temps, j’ai adapté ma CAO pour rendre les pièces imprimables en 3D.
En effet, l’impression 3D a été choisie pour la fabrication des pièces en raison de ses nombreux atouts :

Avantages :

- Flexibilité de conception : Elle permet de réaliser des formes complexes difficiles à obtenir par d’autres procédés.
- Prototypage rapide : Les modifications peuvent être intégrées et testées rapidement.
- Coût réduit : Comparé à d’autres méthodes, elle reste économique pour des productions unitaires ou en petite série.

Inconvénients :

- Tolérances de fabrication : Les écarts dimensionnels liés à l’impression nécessitent des ajustements dans la conception (comme pour le diamètre des trous taraudés).
- Résistance mécanique limitée : Les pièces imprimées ne sont pas aussi robustes que celles fabriquées par injection ou usinage, ce qui limite leur utilisation dans des environnements exigeants.
- Temps de fabrication : Bien que rapide pour un prototype, l’impression 3D reste lente si plusieurs pièces doivent être produites.

À ce stade, la CAO contenait toutes les pièces principales. Cette première version avait pour objectif d’obtenir un aperçu global de l’hovercraft, afin de discuter plus facilement des premiers problèmes identifiés avec le reste de l’équipe, ainsi qu’avec notre aide technique, Pierre ROUX. Il était responsable de la conception mécanique et du prototypage rapide pour les différents projets PIST. Dans un second temps j’ai pu rentrer dans les détails de la conception et finir la première version.

### 2.1.3 Version 0.4

Dans cette version, les modifications suivantes ont été apportées par rapport à la V0.1 :

- Modification du diamètre de prt_upper_bati pour intégrer les tolérances de fabrication avec prt_lift_struct.
- Intégration du servomoteur dans la CAO.

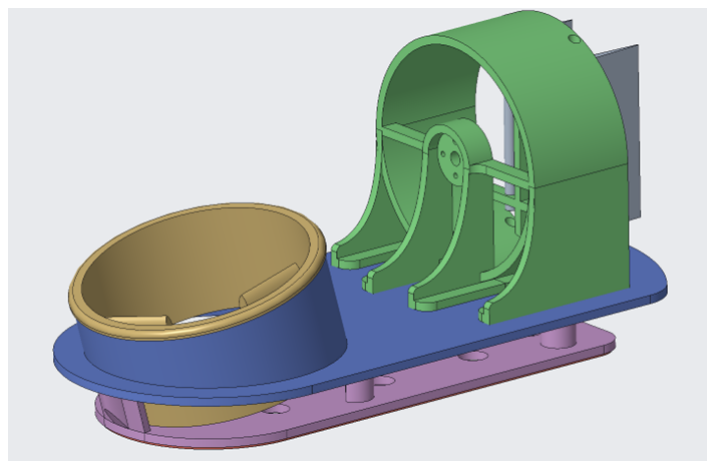
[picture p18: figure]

Figure 6: Version 0.1 de l’hovercraft

- Ajout de prt_rudders_link, une pièce permettant de lier les gouvernails au servomoteur.
- Création des trous pour la visserie.
- Ajout du capteur IR pour la détection de ligne.
- Ajustement des diamètres des trous taraudés (par exemple : diamètre 1,4 mm pour du M2 et 2,3 mm pour du M3).

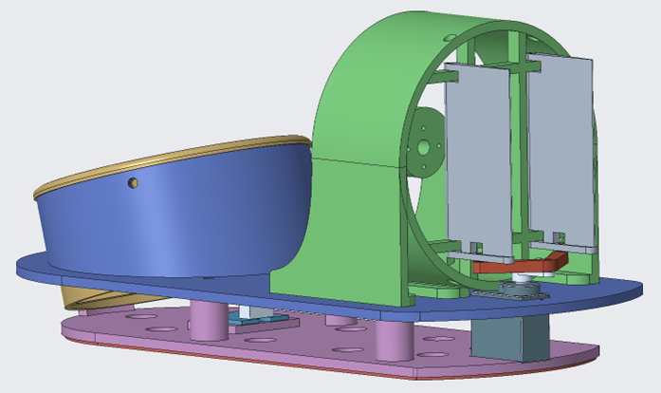
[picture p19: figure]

Figure 7: Version 0.4 de l’hovercraft, vue 1

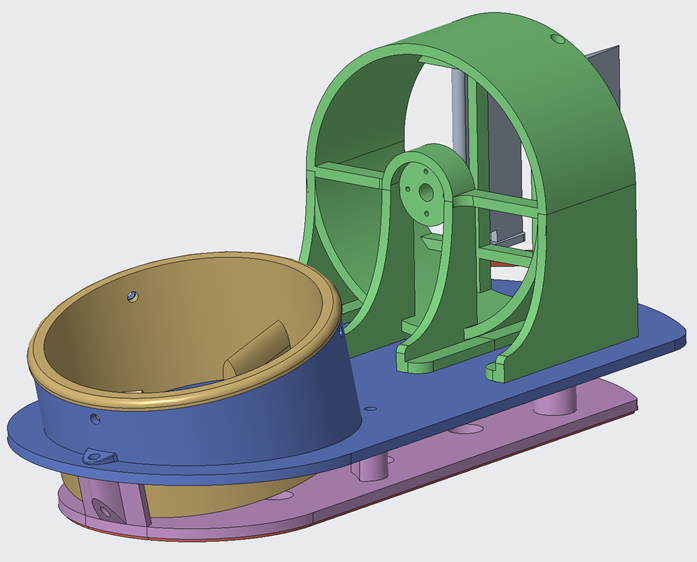
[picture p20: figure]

Figure 8: Version 0.4 de l’hovercraft, vue 1

### 2.1.4 Montage de l’hovercraft

Avec cette version 0.4 de l’hovercraft nous avons pu imprimer toutes les pièces à l’aide de Pierre ROUX, et commencer le montage du premier prototype. Le montage de l’hovercraft comprenait le câblage et la soudure des différents composants puis le vissage des différentes pièces entre elles. Avec enfin la fixation de la jupe à l’aide de clip.
Lors de cette étape, plusieurs problèmes ont été identifiés :
- Défaut de fabrication de la pièce bleue : Au niveau du flanc droit, la pièce était plus fine de 0,5 mm. Cela empêchait les clips de bien tenir la jupe en place. Avec M. ROUX, nous avons supposé que cette anomalie était due à une surchauffe de la pièce pendant l’impression 3D, ce qui a causé un bombement et une réduction de son épaisseur.
- Fragilité des gouvernails : En raison de leur forme particulière, M. ROUX a décidé de les imprimer en résine, ce qui les rendait très cassants. Lors du montage, nous avons cassé les deux pièces et avons même dû en rafistoler une avec de la colle.

Figure 9: Image du clip pour la fixation de la jupe

- Difficulté de vissage : Pendant la conception, j’ai parfois mélangé les trous taraudés et les dégagements pour les vis. Cela a entraîné des assemblages hyperstatiques, compliquant grandement le vissage.
- Problèmes d’alignement des moteurs : Les trous mal dimensionnés et mal positionnés ont causé des frottements entre les hélices et la structure. Pour corriger cela, nous avons dû poncer les parties gênantes.
- Mauvaise intégration des ESCs : En raison du surdimensionnement des ESCs, nous avons dû placer l’un des deux sur le dessus, aux côtés de la batterie, alors que nous avions initialement prévu de les positionner tous les deux en bas.

Voici le résultat final du prototype 1 :

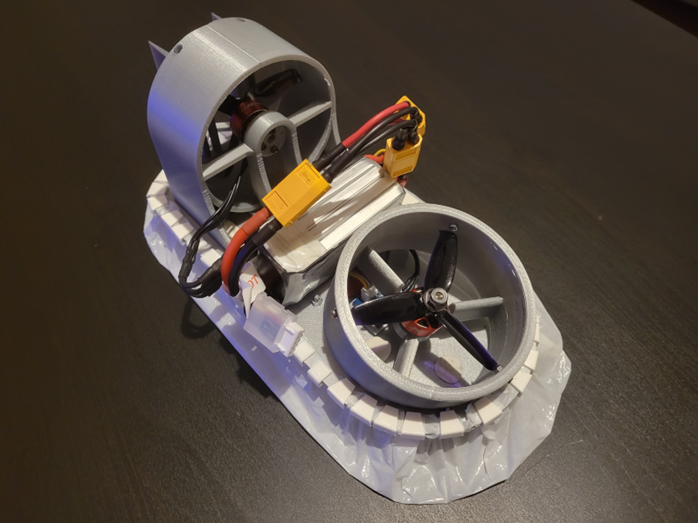
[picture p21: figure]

Figure 10: Résultat du prototypage

### 2.2 Code Arduino (Christophe)

L’arduino qui a été utilisé durant l’ensemble du projet est la Nano 33 BLE Rev2.

### 2.2.1 Première étape de mise en place du code

Le délai pour recevoir la bonne carte Arduino ayant pris du tant, nous avons commencer à travailler sur une Arduino Nano ESP32. L’objectif lors de cette étape était simplement de contrôler un servomoteur similaire à celui que nous utilisons à la fin.
Cela donne ce code qui effectue un contrôle basique d’un servomoteur en réalisant un balayage (sweep) entre deux angles définis, 45° et 135°. L’utilisation d’une interpolation permet un mouvement fluide entre les positions. Cette étape a permis de valider la compatibilité du matériel et de s’assurer que le moteur répondait correctement aux commandes.
Bien que ce servomoteur n’est pas limité en angles, ce qui on été acheté pour la suite du projet le sont. Il peuvent se déplacer de -45° à 45°.

#include <Servo.h>

Servo myServo;
int pos = 0;
int angleMin = 45;
int angleMax = 135;

// MAXIMUM ANGLE STEP FOR 25 DELAY IS 10° IN THE FOR LOOP (pos+=10) IN 1ms IT DOES 0.429° AT ,→ THE MAXIMUM

void setup() {
myServo.attach(9);
| Serial.begin(115200);
myServo.write((angleMin + angleMax) / 2); // Move to a neutral position
| delay(1000); // Let the servo stabilize

}

void loop() {
| static int currentPos = (angleMin + angleMax) / 2; // Start at neutral position
| // Sweep from angleMin to angleMax for (pos = angleMin; pos <= angleMax; pos += 10) { currentPos = currentPos + (pos - currentPos) / 2; // Smooth transition myServo.write(currentPos); // Write the smoothed position delay(25); // Stabilization delay

}

| // Sweep back from angleMax to angleMin for (pos = angleMax; pos >= angleMin; pos -= 10) { currentPos = currentPos + (pos - currentPos) / 2; // Smooth transition myServo.write(currentPos); // Write the smoothed position delay(25); // Stabilization delay

}

}

### 2.2.2 Utilisation du Bluetooth

L’un des premiers problèmes rencontrer était que l’arduino utilise du Blutooth qui est qualifier de BLE, autrement dit Bluetooth Low Energy.
Le Bluetooth Low Energy est une technologie de communication sans fil conçue pour minimiser la consommation d’énergie tout en permettant des échanges de données fiables sur de courtes distances. Contrairement au Bluetooth classique, le BLE est optimisé pour des applications où les transferts de données sont intermittents ou nécessitent une faible bande passante, comme les appareils IoT ou les dispositifs portables.
Dans le cadre de ce projet, l’utilisation de l’Arduino Nano 33 BLE Rev2, équipée de cette technologie, a présenté plusieurs implications :
- Configuration et Communication BLE : Le BLE fonctionne autour du concept de services et de caractéristiques. Il a fallu concevoir une architecture logicielle spécifique où chaque commande de contrôle (comme la vitesse ou la direction) est associée à des caractéristiques BLE distinctes. Cela a nécessité la définition et l’implémentation de UUIDs (identifiants uniques) pour gérer les échanges de données.
- Compatibilité des périphériques : Tous les appareils ne supportent pas nativement le BLE, et des outils spécifiques, comme des applications mobiles ou des logiciels de débogage compatibles BLE. Cela a été le cas lors de la conception de l’application.
- Limitations en débit de données : Étant donné que le BLE est conçu pour des échanges légers, la transmission de données volumineuses ou continues, comme des flux de télémétrie en temps réel, n’est pas optimale. Cela a influencé la conception du système, privilégiant des commandes simples et efficaces pour le contrôle en temps réel.
- Avantages pour l’hovercraft : Grâce à sa faible consommation d’énergie, le BLE a contribué à allonger l’autonomie de la batterie de l’hovercraft, un avantage essentiel pour un dispositif mobile alimenté par une batterie.

Pour tester la compatibilité, nous avons effectué une première ébauche de code que vous pouvez trouver sur le dépôt GitHub du projet. (https://github.com/RomualdBaudri/Hovercraft/commit/3225e7b1cafdfc9a53495653bc4e5069e75b56a1)
Ce code est une première ébauche visant à tester la communication Bluetooth Low Energy (BLE) entre l’Arduino Nano 33 BLE Rev2 et un périphérique externe. Il permet de :
- Contrôler un servomoteur en fonction des données reçues via le BLE, comme une position cible définie par une caractéristique BLE.
- Gérer des LED RGB via des caractéristiques BLE spécifiques pour simuler des actions et visualiser les données reçues.
- Assurer une transition fluide entre les positions cibles du servomoteur pour éviter les mouvements brusques.
- Établir une connexion BLE robuste en annonçant le service et en assurant la gestion de l’état connecté/déconnecté.

Ce prototype a permis de valider la communication BLE, d’établir un contrôle de base, et de poser les fondations pour une intégration plus complète des fonctionnalités du projet.

### 2.2.3 Contrôle du Moteur et des ESC

Le contrôle des moteurs brushless via les ESC a été une étape cruciale du projet. Voici un résumé des principales étapes effectués :

- Choix des ESC : Les ESC sélectionnés sont capables de supporter une charge continue de 40A avec un maximum de 50A, adapté aux moteurs SmooX 1507 Plus - 3800KV. Il a été vérifié que ces ESC disposent d’une compatibilité PWM pour les signaux de contrôle.

- Signal de contrôle PWM : Les moteurs brushless sont contrôlés via les ESC en utilisant un signal PWM. Ce signal, généralement compris entre 1000 µs et 2000 µs, correspond à la puissance sortant de l’ESC, dans ce cas 1000 µs correspond a une sortie de l’ESC de 0A et 2000 µs correspond a 40A. Un réglage fin des timings PWM a été effectué pour garantir une réponse fluide et précise.
- Initialisation des ESC : L’initialisation et la configuration des ESC sont des étapes cruciales pour garantir un fonctionnement optimal et sécurisé du système. Cette procédure se décompose en deux phases principales : la calibration initiale et la programmation des paramètres.

Phase de Calibration

La calibration est nécessaire pour que l’ESC puisse identifier correctement :

– La plage complète des signaux PWM (1000µs à 2000µs)
– Le point neutre (idle) à 1000µs

– La valeur maximale à 2000µs

Procédure de calibration : Il faut faire attention ici lors de la calibration, l’output de l’ESC en 5V ne doit pas être connecté, car l’ESC se met alros en tension depuis l’alimentation USB du PC et cela fausse la calibration.

1. Déconnexion de la batterie
2. Envoi du signal maximum (2000µs)
3. Connexion de la batterie
4. Attente d’environ 2 seconde maximum
5. Envoi du signal minimum (1000µs)
6. Confirmation finale par signal sonore

Phase de Programmation

Après la calibration initiale, l’ESC offre une interface de programmation accessible via une séquence spécifique :

– Activation du mode programmation :
∗ Maintenir le signal neutre pendant 5 secondes après la mise sous tension ∗ L’ESC émet des séquences sonores indiquant les différents paramètres

– Paramètres programmables :

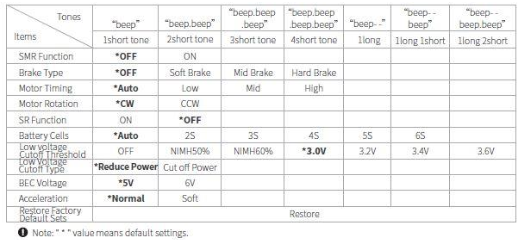
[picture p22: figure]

Figure 11: Tableau présentant l’ensemble des paramètres programmable

Points importants

– La calibration n’est nécessaire qu’une seule fois, sauf en cas de modification des paramètres

– Les paramètres sont conservés en mémoire même après déconnexion

– Une mauvaise calibration peut entraîner :

∗ Des comportements instable du moteur
∗ Une réponse non linéaire aux commandes
∗ Des problèmes de démarrage

– La documentation complète de l’ESC est disponible en annexe pour référence

Note de sécurité : Il est crucial de toujours déconnecter les hélices lors de la calibration et de la programmation des ESC pour éviter tout démarrage accidentel des moteurs.

#include <Servo.h>

// Define signal ranges and pins #define MAX_SIGNAL 2000
#define MIN_SIGNAL 1000

#define MOTOR_PIN 8

#define REVERSE_PIN 7 // Reverse signal wire connected to D7

Servo motor;

void setup() {
Serial.begin(115200);
delay(1500);

Serial.println("Program begin...");
delay(1000);
Serial.println("This program will start the ESC.");

motor.attach(MOTOR_PIN);

// Configure reverse pin
pinMode(REVERSE_PIN, OUTPUT);
digitalWrite(REVERSE_PIN, LOW); // Start in forward mode by default

// ESC calibration
Serial.print("Now writing maximum output: (");
Serial.print(MAX_SIGNAL);
Serial.println(" us in this case)");
Serial.println("Turn on power source, then wait 2 seconds and press any key."); motor.writeMicroseconds(MAX_SIGNAL);
Serial.println("Step 1");

// Wait for input to select the menu while (!Serial.available()); Serial.println("Step 2");
Serial.read();
motor.writeMicroseconds(MIN_SIGNAL);
Serial.println("enter in the menu. Wait for selection of option");

// Wait for input to select the option
while (!Serial.available());
Serial.println("Step 3");
Serial.read();
motor.writeMicroseconds(MAX_SIGNAL);

// Wait for input to be back in the programm selection menu and then go back to ,→ calibration

while (!Serial.available());
Serial.println("Step 4");

Serial.read();
// Send minimum output
Serial.println("\n");
Serial.print("Sending minimum output: ("); Serial.print(MIN_SIGNAL);
Serial.println(" us in this case)"); motor.writeMicroseconds(MIN_SIGNAL);
Serial.println("The ESC is calibrated.");
Serial.println("----");
Serial.println("Type a value between 1000 and 2000 to control the motor."); Serial.println("Send '1000' to stop the motor, '2000' for full throttle."); Serial.println("Send 'R' to toggle reverse mode.");

}

void loop() {
if (Serial.available() > 0) {
String input = Serial.readStringUntil('\n'); // Read input as a string

// Handle reverse mode toggle
if (input.equalsIgnoreCase("R")) {
static bool isReverse = false; // Keep track of reverse state
isReverse = !isReverse; // Toggle reverse state digitalWrite(REVERSE_PIN, isReverse ? HIGH : LOW); // Set reverse signal Serial.print("Reverse mode ");
Serial.println(isReverse ? "activated." : "deactivated.");

}
else { // Handle throttle control
int throttle = input.toInt();
if (throttle >= MIN_SIGNAL && throttle <= MAX_SIGNAL) { motor.writeMicroseconds(throttle); // Send throttle value to ESC

// Calculate motor speed percentage
float speedPercent = (throttle - MIN_SIGNAL) * 100.0 / (MAX_SIGNAL -,→ MIN_SIGNAL);
Serial.print("Motor speed: ");
Serial.print(speedPercent);
Serial.println("%");
} else {
Serial.println("Invalid input! Enter a value between 1000 and 2000 or 'R' to ,→ toggle reverse.");

}

}

}

}

- Problèmes rencontrés et solutions :

– Problème : Parfois, les ESC n’initialisaient pas correctement en raison d’une séquence incorrecte.
Solution : Ajout d’une pause après la mise sous tension pour garantir une initialisation stable.
Explication : Les ESC nécessitent une séquence d’initialisation précise pour calibrer leurs plages de fonctionnement. Cette séquence implique :
∗ Envoi du signal maximum (2000µs)

∗ Attente de la mise sous tension
∗ Envoi du signal minimum (1000µs)
∗ Attente de la confirmation sonore de l’ESC

– Problème : Les moteurs avait tendence à vibrer lors d’une augmentation brusque de la puissance.
Solution : Changer la valeur envoyée de manière plus incrémentale. Le moteur ayant du mal à passer de 0% à 20% d’un seul coup.
Explication : Les moteurs brushless fonctionnent par commutation électronique. Un changement brusque de vitesse peut causer :

∗ Une surcharge momentanée du système
∗ Une désynchronisation entre le rotor et le timing de commutation
∗ Des vibrations dues à la résonance mécanique

– Problème : Surdimensionnement de l’ESC : Les ESC sont surdimensionnés pour le système. Ce qui pose un risque de brûler un moteur, ce qui à été le cas pour nous. Solution : Limitation logicielle de la puissance maximale via le code pour protéger les moteurs.
Explication : Avec un ESC de 40A et un moteur dont la plage de fonctionnement optimale se situe entre 8-10A, avec une capacité maximale de 25A en pic. Pour garantir la durée de vie et les performances du moteur, il est recommandé de ne pas dépasser 12-15A en fonctionnement continu.
∗ Un signal de 1500µs (50%) sur l’ESC peut délivrer jusqu’à 20A
∗ Sous 14.8V (4S), cela représente une puissance de : P = U × I = 14.8V × 20A = 296W
∗ La puissance maximale sécuritaire du moteur est de : Pmax = 14.8V × 10A = 148W
∗ Solution implémentée : limitation du signal à 25% de la plage (1250µs max) pour maintenir le courant sous 10A

– Recommandations pour l’utilisation des ESC :

∗ Toujours commencer avec une valeur de throttle minimale
∗ Modifier la commande pour appliquer un gradient éviter des variations trop brusques, réduisant ainsi les risques de dommage sur le moteur.
∗ Surveiller la température du moteur et de l’ESC
∗ Utiliser des connecteurs adaptés au courant maximal

Ces étapes ont permis d’obtenir un contrôle fiable et stable des moteurs pour assurer la propulsion de l’hovercraft.

### 2.2.4 Code finale du contrôle

Le code pour le contrôle finale de l’hovercraft peut-être trouvé ici. (https://github.com/RomualdBaudri/Hovercraft/blob/Dev-CODE/Code/Hovercraft_Control/Hovercraft_Control.ino)
Ce code permet maintenant le contrôle des deux joystick présent sur l’application. Un pour le contrôle des pâles et un pour la puissance délivrer au moteur.
Voici un résumé des différente fonctionnalité présente dans ce code.

Description du code Arduino : Le programme implémente le contrôle d’un hovercraft via Bluetooth Low Energy (BLE) avec les fonctionnalités suivantes :

- Communication : Utilisation du BLE pour établir une liaison sans fil avec l’appareil de contrôle

- Contrôles principaux :

– Deux moteurs brushless contrôlés par ESC (Electronic Speed Controller)

– Un servomoteur pour la direction

– Un système de LED RGB pour le retour visuel, s’assurer que la carte est bien alimenté.

- Fonctionnalités implémentées :

– Contrôle de la sustentation (moteur de gonflage). Cette partie de code pousse le moteur à fonctionner a 20%. pour cela on incrémente avec un léger délai la puissance envoyer afin de limiter les problème.
– Contrôle de la propulsion (moteur principal)

– Direction via servomoteur

– Détection de ligne par capteur IR, on détecte dans notre cas des lignes noirs.

– Retour d’état via LED RGB

- Sécurité :

– Limitation des signaux ESC entre 1000µs et 1200µs

– Initialisation sécurisée des ESC au démarrage

– Contrôle progressif des changements d’angle du servo

### 2.3 Application Mobile (Christophe)

Présentation de l’application, avec explications sur l’interface et les fonctionnalités. Pour développer l’application nous avons utilisé MIT App inventor 2 (AI2).

### 2.3.1 Première Version

Cette version initiale présentait des fonctionnalités basiques : L’application implémente une connexion Bluetooth Low Energy (BLE) à travers plusieurs étapes :

Gestion de la Connexion Bluetooth LE :

1. Processus de scan :
- Déclenchement du scan via le bouton "ButtonScan"
- Mise à jour de l’interface utilisateur pendant le scan
- Affichage des appareils détectés dans une liste (ListBLE)
2. Établissement de la connexion :
- Sélection d’un appareil dans la liste
- Connexion via "ButtonConnect" à l’appareil sélectionné
- Indication visuelle de l’état de connexion (vert pour connecté, rouge pour déconnecté)

Fonctionnalités implémentées :

- Scan et connexion BLE
- Contrôle directionnel via un joystick virtuel
- Transmission des coordonnées X et Y du joystick

Architecture du joystick :

- Implémentation via un élément "Ball" contraint dans une zone
- Récupération des coordonnées lors du déplacement ("Dragged")
- Transmission des données via BLE lors du relâchement ("TouchUp")
- Envoi des coordonnées au format arrondi pour optimiser la transmission

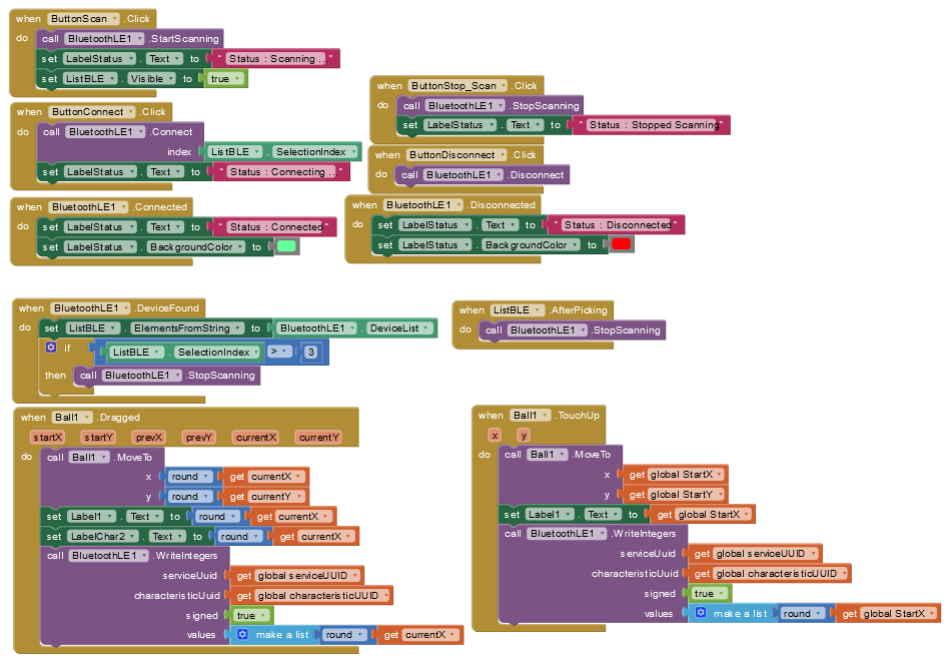
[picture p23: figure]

Figure 12: Code pour la première version de l’application

Limitations identifiées :

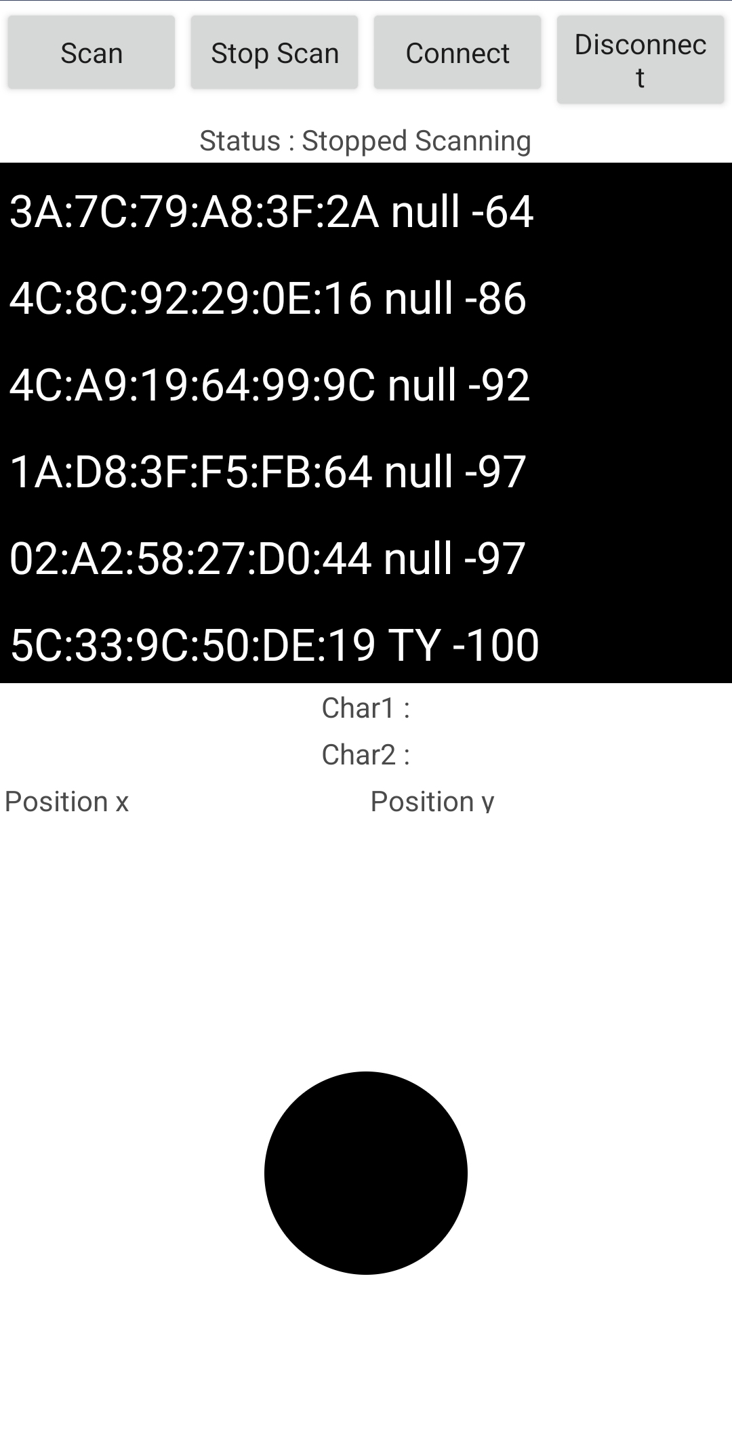
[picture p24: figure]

Figure 13: Première version de l’application

- Problèmes d’interface :

– Scan trop rapide des appareils BLE

– Processus de connexion peu ergonomique

– Interface monolithique sans séparation des fonctionnalités

- Limitations techniques :

– Mouvement non contraint du joystick

– Manque de gestion des erreurs de connexion

Ces limitations ont guidé les améliorations apportées dans les versions ultérieures de l’application.

### 2.3.2 Deuxième version

Cette deuxième version permet une utilisation plus ergonomique pour la connexion. Différent onglets sont créer pour les différentes fonctionnalités.

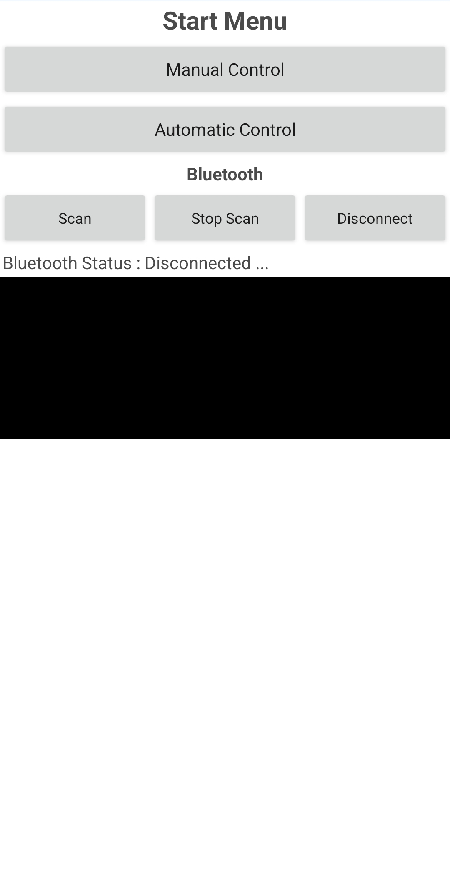
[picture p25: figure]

Figure 14: Start Menu | Figure 15: Contrôle Manuelle

Une difficulté majeure lors du développement a été l’utilisation de l’extension BLE (Bluetooth Low Energy) dans App Inventor 2 (AI2). Pour implémenter les onglets, une astuce a été employée : tous les onglets sont en réalité présents sur un seul écran. L’application utilise des sous-blocs qui peuvent être affichés ou masqués dynamiquement grâce à des boutons, simulant ainsi un système d’onglets.
Dans cette version, une amélioration notable est le mapping des valeurs du joystick, désormais réalisé directement dans l’application plutôt que sur l’Arduino. Ce mapping est essentiel pour convertir les données brutes du joystick en valeurs exploitables par le servomoteur, permettant un contrôle plus fluide et précis.

### 2.3.3 Version Finale

La version finale de l’application intègre plusieurs améliorations pour offrir une expérience utilisateur plus fluide et complète.
Dans cette version, une nouvelle extension d’App Inventor 2 (AI2) a été utilisée pour créer des joysticks plus ergonomiques. Chaque joystick permet un contrôle indépendant : l’un gère le servomoteur, tandis que l’autre contrôle le moteur brushless responsable de la propulsion de l’hovercraft. Un bouton a été rajouter pour mettre en route l’inflation de la jupe de l’hovercraft. De plus, une fonctionnalité dédiée au capteur infrarouge (IR) a été ajoutée pour le comptage de lignes. Contrairement aux versions précédentes, où l’application ne pouvait qu’envoyer des commandes à l’Arduino, cette version permet également au capteur de transmettre des informations vers l’application, qui les affiche en temps réel.
Enfin, une mesure de sécurité a été mise en place : l’utilisateur ne peut accéder aux contrôles de l’application que si la connexion Bluetooth est active, évitant ainsi tout comportement inattendu en l’absence de communication avec l’Arduino.


Figure 16: Start Menu 3rd Version


Figure 17: Manual 3rd Version

### 2.4 Câblage de la carte Arduino (Christophe/Romuald)


Figure 18: Image du circuit Sur l’arduino utilisé

Les câbles jaunes correspondent au signaux PWM. Le cable vert correspond au valeur reçu depuis l’IR. Les câbles rouges sortant des ESC sont des câbles qui alimente en 5V.

Pin | Type de Signal | Fonction
6 | PWM (Jaune) | Contrôle du servo-moteur pour la direction (SERVO_PIN)
3 | PWM (Jaune) | Contrôle du moteur ESC 1 pour la propulsion (MOTOR_PIN_1)
8 | PWM (Jaune) | Contrôle du moteur ESC 2 pour le gonflage (MOTOR_PIN_2)
11 | Digital Input | Capteur IR pour la détection de ligne (signalPin)

Table 3: Attribution des pins sur l’Arduino Nano

### 3 Axes d’Améliorations (Christophe/Romuald)

Suite au développement et aux tests du projet Hovercraft, plusieurs axes d’amélioration ont été identifiés pour optimiser les performances et la fiabilité du système. Ces axes ne sont que des pistes que nous n’avons pas poussé mais qui se basent sur notre expérience actuel et qui pourrait aider à guider la suite du projet.

### 3.1 Améliorations Mécaniques

### 3.1.1 Optimisation de la Sustentation

- Redimensionnement de la jupe pour une meilleure répartition de la pression d’air
- Utilisation de matériaux plus légers pour réduire la masse totale du système

### 3.1.2 Système de Propulsion

- Installation d’un système de refroidissement pour les ESC et moteurs brushless
- Optimisation de la position des hélices pour maximiser la poussée, les hélices actuels ne sont pas adaptées pour maximiser la poussé de l’hovercraft. Il faudrait prendre des hélices symétriques.
- Développement d’un système de protection des hélices contre les débris

### 3.2 Améliorations Électroniques

### 3.2.1 Gestion de l’Alimentation

- Implémentation d’un système de monitoring de la batterie en temps réel
- Ajout d’une protection contre les surintensités pour les moteurs
- Ajout de switch pour couper la batterie

### 3.2.2 Capteurs et Navigation

- Intégration de capteurs de proximité supplémentaires pour une meilleure détection d’obstacles
- Capacité à l’hovercraft de d’avancer et de reculer.
- Ajout d’un système de localisation par fusion de données (IMU + capteurs externes)

### 3.3 Améliorations Logicielles

### 3.3.1 Application Mobile

- Implémentation d’une interface de calibration des moteurs et servomoteurs
- Ajout d’un mode de diagnostic pour le dépannage
- Développement d’une fonctionnalité d’enregistrement des données de navigation

### 3.3.2 Firmware Arduino

- Implémentation d’un système de gestion des erreurs plus robuste
- Développement d’un mode de navigation autonome

### 3.4 Améliorations des Performances

### 3.4.1 Navigation Autonome

- Amélioration de la précision du comptage de tours

### 3.4.2 Contrôle et Stabilité

- Mise en place d’un PID pour le contrôle de la direction
- Optimisation des paramètres de contrôle pour une meilleure réactivité
- Développement d’un système de stabilisation automatique

### 3.5 Maintenance

### 3.5.1 Facilité de Maintenance

- Conception modulaire pour un remplacement facile des composants
- Amélioration de l’accessibilité aux composants critiques (Carte Arduino en particulier)

### 4 Conclusion

### 4.1 Rappel des objectifs et innovation

Le projet Hovercraft avait pour ambition de concevoir un système compact, autonome, et performant, capable de répondre à des critères exigeants d’innovation mécanique, électronique et logicielle. L’objectif principal ,pour nous, était de réaliser l’étude préliminaire et de créer une preuve de concept en réalisant un hovercraft contrôler manuellement.
Malgré des défis importants, notamment liés aux délais d’approvisionnement et aux contraintes de conception, nous avons réussi à créer un prototype fonctionnel et à poser les bases pour des évolutions futures.

### 4.2 Rétrospective sur le CDCF

Le Cahier des Charges Fonctionnel (CDCF) a guidé l’ensemble des phases de développement, servant de référence pour évaluer les progrès et les priorités. Parmi les objectifs principaux :

- Réussites :

– L’hovercraft est capable de se déplacer.
– La détection de lignes noires au sol a été implémentée avec succès, répondant aux critères définis.
– Le contrôle à distance via une application mobile BLE est fonctionnel, offrant une interface intuitive et ergonomique.
- Limites :

– Le poids total du prototype dépasse légèrement l’objectif de 500 g, en raison de la nature des composants utilisés et des contraintes du prototypage rapide.
– La robustesse des matériaux, bien que suffisante pour des tests en environnement contrôlé, pourrait être améliorée pour des usages prolongés. En particulier les hélices guider par le servomoteurs

### 4.3 Retour sur le développement

Le développement de ce projet a permis de relever des défis techniques variés dans les domaines mécanique, électronique et logiciel :

- Aspect mécanique : La conception en CAO a permis de réaliser un châssis optimisé, bien que certains ajustements aient été nécessaires pour compenser les limitations de l’impression 3D.
- Aspect électronique : La calibration et le contrôle des ESC ont été maîtrisés (non sans mal), et les capteurs infrarouges ont été intégrés avec succès pour la détection de lignes.
- Aspect logiciel : L’application mobile BLE, couplée à des algorithmes de contrôle progressif des moteurs, a offert une interface stable et des performances satisfaisantes. Cependant, la gestion des interférences BLE pourrait être améliorée.

### 4.4 Impact du projet et perspectives

Ce projet a permis de développer des compétences techniques variées, notamment en conception mécanique, en programmation et en électronique embarquée. Il a également renforcé notre capacité à travailler en équipe et à résoudre des problèmes complexes. L’hovercraft ainsi conçu constitue une base solide pour des développements futurs.

### 4.5 Conclusion générale

En conclusion, ce projet a atteint ses objectifs principaux tout en offrant une expérience enrichissante pour l’ensemble des participants. Malgré certaines limites, les résultats obtenus témoignent de la faisabilité d’un hovercraft compact, intégrant des technologies avancées. Nous espérons que ce travail servira de point de départ pour d’autres équipes qui souhaiteront explorer et améliorer cette plateforme.

### Annexes

### A Bibliographie/Netographie

Différente vidéo qui ont inspiré le projet et permis de mieux comprendres les attentes

- Première vidéo How I 3D Printed a FAST RC Hovercraft (https://youtu.be/pHdO_BtYl7M?si=gNCbQNsHF09yxt5n) .
- Deuxième vidéo 3D Printed RC Hovercraft on SPEED! (https://youtu.be/rCYRUXrFhZc?si=Uk7E6UAYJc8c9xqP) .
- Lien vers le forum. (https://www.thingiverse.com/thing:2700850)

### B Lien Github du Projet

Attention on différente branche du projet. La majorité se trouvant des les branches DEV-CAO et DEV-CODE

- Github du projet. (https://github.com/RomualdBaudri/Hovercraft)

### C Documentations Associées

Liens vers la documentation des composants utilisés. Certaines des documentations sont en Allemands. La majorité en Anglais.

- Drive avec les documentations. (https://drive.google.com/drive/folders/1frXN_9IN8mSaBTqvfHWEagb69dfuotS7?usp=sharing)

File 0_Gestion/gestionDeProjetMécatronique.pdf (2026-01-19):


É C O L E N A T I O N A L E S U P É R I E U R E D E M É C A N I Q U E E T D E S M I C R O T E C H N I Q U E S | 1

# Gestion de projet mécatronique

# Guillaume LAURENT

# Les quatre étapes d’un projet : 1. Lancement (MOA)


É C O L E N A T I O N A L E S U P É R I E U R E D E M É C A N I Q U E E T D E S M I C R O T E C H N I Q U E S | 2

# 2. Planification (MOE) 3. Réalisation (MOE + équipes + sous-traitants) 4. Recette et clôture (MOA)

# Maîtrise d’ouvrage (MOA) et maîtrise d’œuvre (MOE)

É C O L E N A T I O N A L E S U P É R I E U R E D E M É C A N I Q U E E T D E S M I C R O T E C H N I Q U E S | 3

# I. Lancement du projet


É C O L E N A T I O N A L E S U P É R I E U R E D E M É C A N I Q U E E T D E S M I C R O T E C H N I Q U E S | 4

L'objectif du projet est de réaliser un robot mobile pour participer à un tournoi comportant deux épreuves mulympiques : la vitesse et le poids.

Règlement : le robot doit n'avoir que deux roues en contact avec le sol et tenir dans un volume de 30x15x10 cm. Il doit peser 300g au maximum et avoir une autonomie d'au moins 5 min.

# Lancement du projet

É C O L E N A T I O N A L E S U P É R I E U R E D E M É C A N I Q U E E T D E S M I C R O T E C H N I Q U E S | 5

# II. Planification du projet

(norme NF E01-010); Ingénierie pluridisciplinaire ▪ Mécanique ▪ Electronique ▪ Automatique ▪ Informatique; Objectifs; ▪ Innovation ▪ Augmentation des fonctionnalités; ▪ Réduction du coût ▪ Augmentation de la productivité; Traitement du signal; Capteurs; Lois de commande; Actionneurs

É C O L E N A T I O N A L E S U P É R I E U R E D E M É C A N I Q U E E T D E S M I C R O T E C H N I Q U E S | 6

Synergie de la mécanique, l’électronique, l’automatique et l’informatique dans la conception et la

# fabrication d’un produit en vue d’en augmenter sa fonctionnalité

# - Réduction de la consommation énergétique

# Ingénierie mécatronique


É C O L E N A T I O N A L E S U P É R I E U R E D E M É C A N I Q U E E T D E S M I C R O T E C H N I Q U E S | 7

« Un système est un ensemble d'éléments en interaction dynamique, organisés en fonction d'un

# but. » Joel de Rosnay (1975)

Norme ISO/IEC/IEEE 15288, publiée le 16 mai 2023 : Ingénierie des systèmes et du logiciel –

# Processus du cycle de vie du system (Systems and software engineering – System life cycle processes)

# Modèle standard d’organisation des projets => cycle en V

# Ingénierie des systèmes


É C O L E N A T I O N A L E S U P É R I E U R E D E M É C A N I Q U E E T D E S M I C R O T E C H N I Q U E S | 8

# Projet piloté par les tests !!

# Cycle en V


É C O L E N A T I O N A L E S U P É R I E U R E D E M É C A N I Q U E E T D E S M I C R O T E C H N I Q U E S | 9

# Cycle en V

É C O L E N A T I O N A L E S U P É R I E U R E D E M É C A N I Q U E E T D E S M I C R O T E C H N I Q U E S | 10

# Définir les critères de réussite du projet

# Tests d’acceptation par l’utilisateur ou le marché

# Exemple de recette pour le tournoi :

# - Participer aux épreuves - Finir dans le top 3 des 10 étables en lice

## - Epater les profs

# Recette

# Définir les contours du projet pour mener à sa réussite

# Expression des besoins


É C O L E N A T I O N A L E S U P É R I E U R E D E M É C A N I Q U E E T D E S M I C R O T E C H N I Q U E S | 11

# Outils :

# - Bête à corne, diagramme pieuvre (APTE) - Story mapping (SCRUM) - Cas d’utilisation (SysML)

## Diagramme pieuvre

# Exemple de bête à corne pour le tournoi

# Expression des besoins

sol; Hauteur max 30cm; Largeur max 15cm Longueur max 10cm; Autonomie min 5min Masse max 300g; Besoins Contraintes; Etudiant; Course; Robot mobile

Aller le plus vite
possible avec un robot
mobile en équilibre

Porter le plus lourd
en équilibre

Deux roues en contact avec le

Gagner la course

Projet de l’option SMR
ENSMM


É C O L E N A T I O N A L E S U P É R I E U R E D E M É C A N I Q U E E T D E S M I C R O T E C H N I Q U E S | 13

# Cycle en V

É C O L E N A T I O N A L E S U P É R I E U R E D E M É C A N I Q U E E T D E S M I C R O T E C H N I Q U E S | 14

# Vérifier la conformité au cahier des charges fonctionnel

# Tests contractuels !!!

# Exemples des tests de validation pour le tournoi :

# - Tenir en équilibre pendant 30 secondes - Tenir en équilibre pendant 30 secondes avec une charge de 50g

## - Parcourir 2 mètres sans tomber

# - Parcourir 2 mètres sans tomber en moins de 10 secondes

# Validation (tests de conformité)


É C O L E N A T I O N A L E S U P É R I E U R E D E M É C A N I Q U E E T D E S M I C R O T E C H N I Q U E S | 15

# Du "pourquoi" au "comment"

# Exigences fonctionnelles

# Exigences non fonctionnelles (contraintes techniques, qualité, etc)

# Outils :

# - Cahier des charges - FAST - SADT - SysML

# Spécifications fonctionnelles

Diagramme FAST

Solutions techniques; Fonctions techniques; Fonction d’usage; Avancer le plus rapidement possible sans tomber; Tenir en équilibre; Centrale inertielle; Microcontrôleur; Avancer; Moteurs; Batterie

É C O L E N A T I O N A L E S U P É R I E U R E D E M É C A N I Q U E E T D E S M I C R O T E C H N I Q U E S | 16

# Exemple de diagramme FAST pour le tournoi

# Spécifications fonctionnelles


É C O L E N A T I O N A L E S U P É R I E U R E D E M É C A N I Q U E E T D E S M I C R O T E C H N I Q U E S | 17

# Cycle en V

É C O L E N A T I O N A L E S U P É R I E U R E D E M É C A N I Q U E E T D E S M I C R O T E C H N I Q U E S | 18

# Vérifier que tout fonctionne ensemble

# Exemples de tests d’intégration pour le tournoi :

- Vérifier que les composants mécaniques s’assemblent et fonctionnent toujours une fois assemblés

# - Mesurer l’autonomie - Tenir en équilibre

# Tests d’intégration


É C O L E N A T I O N A L E S U P É R I E U R E D E M É C A N I Q U E E T D E S M I C R O T E C H N I Q U E S | 19

# Identifier les sous-systèmes

# - Capteurs ? - Actionneurs ? - Pièces mécaniques ?

## - Lois de commandes ?

# - Electronique ?

# Conception architecturale

Diagramme architectural

Centrale inertielle; Contrôleur; Groupe motopropulseur 1; Batterie; Groupe motopropulseur 2; Roue 1; Roue 2

É C O L E N A T I O N A L E S U P É R I E U R E D E M É C A N I Q U E E T D E S M I C R O T E C H N I Q U E S | 20

# Exemple de diagramme architecturale pour le tournoi

# Conception architecturale

Transmission
d’énergie électrique

Transmission
d’informations

Transmission
d’énergie mécanique


É C O L E N A T I O N A L E S U P É R I E U R E D E M É C A N I Q U E E T D E S M I C R O T E C H N I Q U E S | 21

# Cycle en V

É C O L E N A T I O N A L E S U P É R I E U R E D E M É C A N I Q U E E T D E S M I C R O T E C H N I Q U E S | 22

# Vérifier le fonctionnement de chaque composant

# Eviter les régressions (conserver les tests unitaires !!!)

# Exemples des tests unitaires pour le tournoi :

# - Mesurer l’inclinaison du robot - Appliquer une vitesse/couple linéaire sur les moteurs

## - Mesurer la période d’échantillonnage

# - Mesurer le temps de réponse des moteurs

- Etc.

# Tests unitaires

É C O L E N A T I O N A L E S U P É R I E U R E D E M É C A N I Q U E E T D E S M I C R O T E C H N I Q U E S | 23

# Conception/choix des composants

# Interne / externe

# Exemples pour le tournoi :

# - Centrale inertielle - Contrôleur

## - Batterie

# - Groupe motopropulseur - Châssis et connexions électriques

# Conception détaillée

É C O L E N A T I O N A L E S U P É R I E U R E D E M É C A N I Q U E E T D E S M I C R O T E C H N I Q U E S | 24

# Fonction : mesurer l’inclinaison du robot

# Choix de la centrale inertielle


É C O L E N A T I O N A L E S U P É R I E U R E D E M É C A N I Q U E E T D E S M I C R O T E C H N I Q U E S | 25

# Choix : Joy-IT SEN-MPU6050

# Fonction 1 : réguler l’inclinaison du robot Fonction 2 : communiquer avec le PC


É C O L E N A T I O N A L E S U P É R I E U R E D E M É C A N I Q U E E T D E S M I C R O T E C H N I Q U E S | 26

# Fonction 3 : stocker des données

# Choix : Arduino MKR

# Choix du contrôleur

É C O L E N A T I O N A L E S U P É R I E U R E D E M É C A N I Q U E E T D E S M I C R O T E C H N I Q U E S | 27

# Fonction : propulser le robot

# Conception du groupe motopropulseur

Transmission
d’énergie électrique

Transmission
d’informations

Transmission
d’énergie mécanique

Groupe motopropulseur

Carte de pilotage
(driver)
Moteur | Réducteur
Batterie | Contrôleur

Roue 2

# Fonction : propulser le robot

# Conception du groupe motopropulseur


É C O L E N A T I O N A L E S U P É R I E U R E D E M É C A N I Q U E E T D E S M I C R O T E C H N I Q U E S | 28

# Choix des composants :

# - Moteur à courant continu 6V Polulu HP 989 - Carte de pilotage 2x1,2A pour deux moteurs à courant continu Polulu DRV8835 - Réducteur 50:1 Polulu HP 998 - Paire de supports moteurs Polulu 989 - Paire de roues noires Pololu Ø80 x 10 mm

# Fonction : alimenter le robot en énergie électrique

# Choix de la batterie


É C O L E N A T I O N A L E S U P É R I E U R E D E M É C A N I Q U E E T D E S M I C R O T E C H N I Q U E S | 29

# Choix : Batterie LiPo PR523450


É C O L E N A T I O N A L E S U P É R I E U R E D E M É C A N I Q U E E T D E S M I C R O T E C H N I Q U E S | 30

# Fonction : maintenir les éléments entre eux Fonction : permettre les échanges d'énergie et d’information

# Châssis et connexions électriques

Découpe laser de plexiglas (PMMA) | Plaque de montage rapide


É C O L E N A T I O N A L E S U P É R I E U R E D E M É C A N I Q U E E T D E S M I C R O T E C H N I Q U E S | 31

Ressources humaines : deux ingénieurs juniors pendant une semaine soit 10 jours-personnes soit

# 2000 € (avec charges patronales)

# Matériel :

# Budget

É C O L E N A T I O N A L E S U P É R I E U R E D E M É C A N I Q U E E T D E S M I C R O T E C H N I Q U E S | 32

# Planification du projet


É C O L E N A T I O N A L E S U P É R I E U R E D E M É C A N I Q U E E T D E S M I C R O T E C H N I Q U E S | 33

# Cycle en V

# Identifier et organiser les taches

# - Tâches préliminaires, intermédiaires et terminales ?

É C O L E N A T I O N A L E S U P É R I E U R E D E M É C A N I Q U E E T D E S M I C R O T E C H N I Q U E S | 34

# - Séquence des tâches ? - Qui va travailler sur quoi ?

# Planification du projet

# Planification du tournoi (PERT)

## Tests d’intégration

Assemblage mécanique; Test des moteurs; Mesure de l’inclinaison; Vérifier que tout fonctionne ensemble; Régulation de l’équilibre; Test de l’autonomie; Test de l’Arduino (blink, serial); Mesure de l’inclinaison avec Simulink; Program- mation avec Simulink; Test des moteurs avec Simulink; Tenir en équilibre pendant 30 secondes; Tests unitaires; Validation; Parcourir 2 mètres sans tomber; Tracer une réponse indicielle

Test de la
centrale
inertielle

Régulation à la
verticale (robot
tenu par les
oreilles)

Test du soft
timer

É C O L E N A T I O N A L E S U P É R I E U R E D E M É C A N I Q U E E T D E S M I C R O T E C H N I Q U E S | 36

# III. Réalisation du projet

# A vous de jouer !

É C O L E N A T I O N A L E S U P É R I E U R E D E M É C A N I Q U E E T D E S M I C R O T E C H N I Q U E S | 37

# IV. Recette et clôture

# Rendez-vous vendredi à 10h pour compter les bouses !

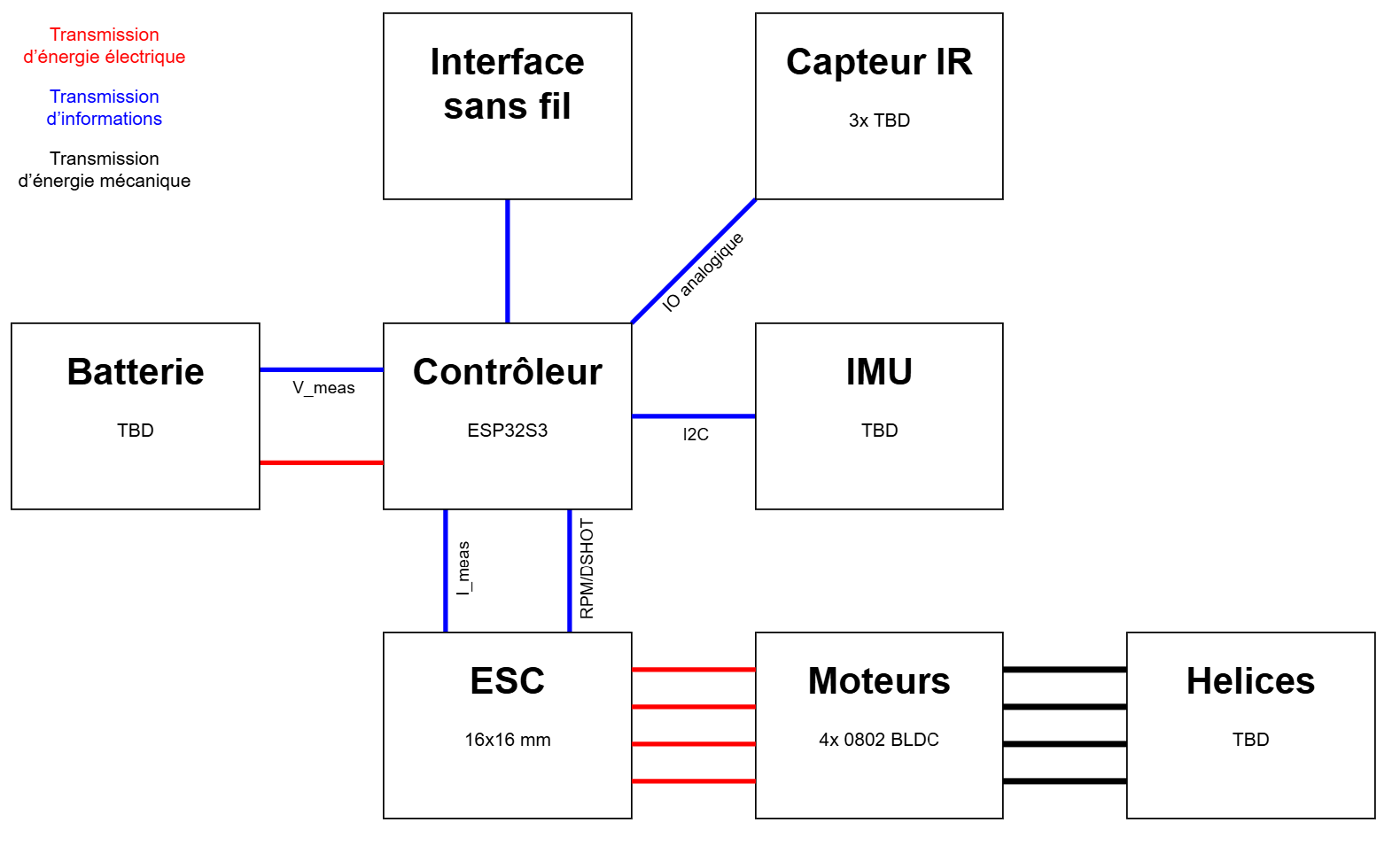
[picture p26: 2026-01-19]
5_Documentation/ConceptionArchitecutrale.png

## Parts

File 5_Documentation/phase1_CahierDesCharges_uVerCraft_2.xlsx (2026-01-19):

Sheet: Planification
Noms: Leon VOLLES, Luis GÖBES |  | Titre du projet |  |  |  |  |  |  |  |  |  |  |  |  |  |  |  |  |  |  |  |  |  |  |  |  |  |  | Date de statut
Responsable: | Mr. Emmanuel PIAT | Projet PIST: µ-verCraft |  |  |  |  |  |  |  |  |  |  |  |  |  |  |  |  |  |  |  |  |  |  |  |  |  |  | 2025-12-16
Nb. |  |  | Statut de | Année | 2025 |  |  |  |  |  |  |  |  |  |  |  |  |  |  |  |  | 2026
 | Activité |  | traitement | Mois | Septembre |  |  |  | Octobre |  |  |  |  | Novembre |  |  |  | Décembre |  |  |  | Janvier |  |  |  |  | Février |  |  |  | Mars
 |  |  | 0-9 | Semaine calendaire | 36 | 37 | 38 | 39 | 40 | 41 | 42 | 43 | 44 | 45 | 46 | 47 | 48 | 49 | 50 | 51 | 52 | 1 | 2 | 3 | 4 | 5 | 6 | 7 | 8 | 9 | 10 | 11 | 12 | 13
 | Date de début: |  | 12.09.2025
1 | Définition du projet |  | 9
2 | Familiarisation avec les bases |  | 9
3 | Liste des exigences (CDCF) |  | 9
4 | Matrice de décision et solution |  | 9
5 | Concept (CAO approximative) |  | 9
6 | Commande de matériel (Moteur, ESC, uControlleur, etc.) |  | 8
7 | CAO précise |  | 8
8 | Construction chassis et montage |  | 2
9 | Programmation |  | 3
10 | Tester et valider |  | 1
11 | Écriture rapport et documentation |  | 1
 |  |  | ~9/01/2026
 | Etapes importantes
 | Vacances scolaires
 | Revue de projet
 |  |  |  |  |  |  |  | 1 |  |  |  | 2 |  |  |  |  |  |  |  | 3 |  |  |  |  | 4
 | Responsable indisponible
 | Période d'examen et préparatifs
Etapes importantes
1 | Projet approuvé
2 | Consigne écrite
3 | Liste des exigences approuvée
4 | Concept développé
5 | Commande passée
6 | Construction finalisée
7 | Programmation
8 | Validation des toutes les testes
9 | Date limite de remise du projet
10 | Presentation final

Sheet: ListeDesExigences
Prof. Piat Construction et gestion de produits SUPMICROTECH-ENSMM |  |  |  | Liste des exigences pour µ-verCraft | Commande: XXX Numéro de commande: / Semestre d'hiver 2025/26 |  |  |  | Resultat / Validation
Données organis. |  | Données du processus |  | Exigences | Valeur - Données
Nb. | Nom | Type | Phase |  | Réalisation minimale | Réalisation satisfaction | Réalisation idéale | Unité |  | Unit Test
 |  |  |  | Fonction physique et technique
F01 |  | E |  | Dimensions | <200x100 | <180x90 | <140x90 | mm | 106x84mm | measure
F02 |  | E |  | Poids | <500 | <300 | <100 | g | 79,95g | measure
F03 |  | E |  | Autonomie de la batterie | >2 | >4 | >6 | min | 4-8 min
F04 |  | E |  | Fond de route | Plane | Plane | Légères irrégularités |  | Variable avec paramètre
F05 |  | S |  | Course autonome sur circuit | Télécommandée | Autonome 180° autour d'un porteu | Autonome un tour complet |  | orientation avec boussole, detection lignes
F06 |  | S |  | Tolerance rotation angulaire | +-20% de la comand | +-10% de la comand | +-5% de la comand |  | PID sans oscillation
F07 |  | E |  | Localisation | Marquages au sol | Marquages au sol | Marquages + Suivi des mouvements |  | Marquages + boussole
F08 |  | S |  | Capteurs marquages | 2 capteur IR | 3 capteurs IR | 3 capteur de flux optique |  | 3 capteurs IR | test unitaire de foncionnment des capteurs
F09 |  | E |  | IMU | Capture 6-DOF | 6-DOF + Filtre intégré | 6-DOF + Filtre + Suivi de vie |  | 6-DOF + boussole!!
F10 |  | E |  | Recalibrage de la pose avec des marquages | 1 paramètre | 2 paramètre | 3 paramètre |  | Calculer Theta + vPerp | passer sur un ligne, deduire la vitesse perpendiculaire, orientation/rotation ou pos./vitesse y
F11
F12
F13
F14
F15
 |  |  |  | Technologie - Fabrication et assemblage
T01
T02
 |  |  |  | Économie
E01 |  |  |  | Prix des composants | <300 | <200 | <100 | € | 198.08 €
 |  |  |  | Relation homme-produit
R01 |  |  |  | Télécommande | BT + application | BT/WiFi | WiFi + site web |  | WiFi + site web | Envoy des signaux type "avace vitesse 10%, ...", verifier avec µC
R02 |  |  |  | Indicateur de niveau de batterie | - | LED pulse/PWM | LED couleur |  | LED + site web | brancher un alimentation de laboratoire, valider que LED change l'état
 |  |  |  | Utilisation, entretien, maintenance
U01 |  |  |  | Mises à jour micrologicielles | Câble USB | Câble USB | Sans fil |  | Câble USB
U02
Types d'exigences: O/N-Oui/Non; E-Exigence; S-Souhait Phase de conception: P-Principe ; C-Concept ; D-Design ; R-Réalisation
Remplace l'édition: / de: / |  |  |  |  | Édition actuelle: de: 17/01/2026

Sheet: CycleEnV
 |  |  |  |  |  |  |  |  | valeur necessaire | idée de resoudre
Définition des besions (cdc fonctionel / fonctions souhaité) |  |  |  |  |  |  |  | Recette
Allez tout droit jusqu'à la ligne, tourner ~180° autour du poteau |  |  |  |  |  |  |  |  | +-20° bien tourné aprés
Mode "telecommandé": Suivre des commandes à distance le mieux possible |  |  |  |  |  |  |  | suffisament reactive, que c'estfesable sans d'entrainement
 | Spécification (cdc f -> cdc t) "architecture de haut niveau" |  |  |  |  |  | Valiation
 | Rotation autour achse z avec une angle défini |  |  |  |  |  | commander 90°, voir si le resultat et +-9° dans les valeur demandé |  | +-10% erreur | thrust-vectoring + PID sur angle IMU
 | Télécommand des mouvement |  |  |  |  |  | Envoy des signaux type "avace vitesse 10%, ...", verifier avec µC (delais par camera) |  | +-1% erreur, delais < 250ms
 | Approximer l'orientation/angle relative par un ligne passé |  |  |  |  |  | appareil explique au TD |  | +-10% erreur
 | Positionement dans l'éspace |  |  |  |  |  | ??? necessaire/comment??? |  | ???
 | Informer utilisateur si tension faible par LED &/ WiFi |  |  |  |  |  | brancher un alimentation de laboratoire, valider que LED change l'état |  | voir CDC
 |  | Conception générale ("modules") |  |  |  | Tests d'intégration
 |  | generation de poussée verticale (Schub/Hub erzeugen) |  |  |  | >60gF/moteur avec helice, en cas de 2 moteur vertical; datasheet suffit
 |  | generation de rotation autour achse z |  |  |  | utilisation de 2 moteur pour faire tourner le hovercraft
 |  | Stabilisation de la rotation autour de l'axe z |  |  |  | donner des petites perturbations ext. Avec un stylo / simialire, voir si la pertubation est corrigé
 |  | mesure d'angle |  |  |  | tourner IMU de qqc degrées, regarder le valeur sorti |  |  | +-1% erreur | avec IMU: intégration des accellerations autour achse z
 |  | Créer des coussins d'air |  |  |  | Active les cussion, faire glisser le aeroglisseur ext. Avec un stylo ou simialire
 |  | Envoyer des signaux à distance |  |  |  | envoyer des signaux par un appareil, recevoir les signaux sur le µC
 |  | Alimentation en énergie |  |  |  | Verifier si la source est dans la bonne plage, mettre un infor pour utiliateur si tension trop bas
 |  | ?? Measure du courant de la Source d'energie?? |  |  |  | activer le moteur, regarder avec capteur et mulimetre
 |  | ?? Measure de la tension de la Source d'energie?? |  |  |  | Multimetre |  |  |  | LED flash si le niveau est bas ( warning), LED allumée en permanence si le niveau est extrêmement bas (utilisation des moteurs désactivée); alternative: utilisation des coleurs de la LED
 |  | Positionnement dans l'espace |  |  |  | Bouger sur un ligne, regarder si cest enregistrer
 |  | Vitesse dans l'espace |  |  |  | definir un longeur specific au sol, measurer le temps de deplacement en ligne droit, comparer vitesse theorique et reel |  |  | +-25% | integration de la IMU?
 |  |  | Conception détaillée (composantes) |  | Test unitaire
 |  |  | Moteur électrique |  | Faire tourner le moteur dans le sense souhaité
 |  |  | IMU |  | Sortir des accelerations sur 6 achses
 |  |  | Source d'energie |  | Measurer la tension |  |  |  | tension entre 3V et 8V | LiPo 1s ou 2s
 |  |  |  | Réalisation

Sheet: RecetteEtTestDeVal
Fonction | Test de validation | Demande
 |  | valeur necessaire | Résultats | idée de resoudre
Définition des besoins (cdc fonctionnel / fonctions souhaités) | Recette
Aller tout droit jusqu'à la ligne, tourner ~180° autour du poteau | validation qualitative, résultat de tts les autres fonctions enchaînées | validation qualitative, ideal: +-20° bien tourné aprés | Séquence simple avec boussole comme point de consigne (après filtre complémentaire), correction possible par lignes
Mode "telecommand": Suivre des commandes à distance le mieux possible | validation qualitative, suffisament reactive, que c'est faisable sans d'entraînement | validation qualitative | Vitesse "Luis" copatible :D
Spécification (cdc f -> cdc t) "architecture de haut niveau" | Validation
Rotation autour axe z avec une angle défini | commander 90°, voir si le resultat et +-9° dans les valeur demandé | +-10% erreur | Commande (-90°): depart 239° boussole, arrivée à 144° -> 95°; oscilaltion +-2° | thrust-vectoring + PID sur angle IMU
Télécommand des mouvement | Envoyer des signaux type "avance vitesse 10%, ...", vérifier avec µC (délai par camera) | +-1% erreur, délai < 250ms | <70,8 ms dèlai (SloMo-Vid 240 fps)
Approximer l'orientation/angle relative par un ligne passée | appareil/methode explique au TD | +-10% erreur | 45,0° -> 46,5° mesuré
Positionement dans l'espace | passer une ligne, comparerr position évaluée par µC avec réalité/measure externe | +-50% erreur | Difficile à évaluer avec measurement externe | combinasition ligne+IMU_angle+IMU_vitesse
Informer utilisateur si tension faible par LED &/ WiFi | brancher une alimentation de laboratoire, valider que LED change l'état | voir CDC | LED + site web | LED flash si le niveau est bas ( warning), LED allumée en permanence si le niveau est extrêmement bas (utilisation des moteurs désactivée); alternative: utilisation des couleurs de la LED
Conception générale ("modules") | Tests d'intégration
Generation de poussée verticale (Schub/Hub erzeugen) | >60gF/moteur avec helice, en cas de 2 moteur verticale | datasheet suffit | Datasheet: ~140gF/moteur
Generation de rotation autour axe z | envoyer signale, observer vitesse de rotation et dépassement | validation qualitative | reglable avec rates/html | differential-thrust: utilisation de 2 moteurs pour faire tourner le hovercraft
Stabilisation de la rotation autour de l'axe z | donner de petites perturbations ext. avec un stylo / similaire, voir si la perturbation est corrigée | validation qualitative |  | PID
Mesure d'angle | tourner IMU de qqc degrés, vreifier avec Geo-Triangle | +-10% erreur | Filtre complementaire: rotation (-90°): depart 239° boussole, arrivée à 144° -> 95° | avec IMU: intégration des accélérations autour axe z
Créer des coussins d'air | Allumez l’aéroglisseur sur une planche. Inclinez la planche à partir de l’horizontale jusqu'à ce que l'aéroglisseur commence à planer | validation qualitative | >>10mm (140g Pousse_Max/Moteuer * 2)
Envoyerer des signaux à distance | envoyer des signaux par un appareil, recevoir les signaux sur le µC | par ex. via serial-out | Affichage Voltage Application | WiFi / Bluetooth
Measure du courant de la Source d'energie | activer le moteur, regarder avec capteur et mulimetre | -0.15 A | Capteur courant intégré dans ESC | Resisteur Shunt (sur ESC si possible), IO analogique sur µC
Measure de la tension de la Source d'energie | multimetre | +-0,1V | <0.01V, ADC 12bit et diviseur de tension | Diviseur de tesion, IO analogique sur µC
Positionnement par rapport à une ligne | Bouger sur un ligne, regarder si c'est enregistré | +-10° | Validation par règle triangulaire | test discuté au cours
Vitesse dans l'espace | definir un longeur specific au sol, measurer le temps de deplacement en ligne droit, comparerr vitesse theorique et reel | -0.25 | Diffice de measusrer, vu que angle est bon, c'est aussi validé | integration de la IMU?
Conception détaillée (composantes) | Test unitaire
Moteur électrique | Faire tourner le moteur dans le sense souhaités | ramp RPM 0% -> 100% -> 0% -> -100% ->0% | validé | Dshot 600
IMU | Sortir des accelerations sur 6 axes | valider les senses de rotation autour des 3 axes (qualitaive) | validé
Source d'energie | multimetre | tension entre 3V et 8V | validé | LiPo 1s ou 2s
Réalisation

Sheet: EvaluationDesFacteurs
Critère | Efficacité énergétique du vol | Robustesse en collision | Coût | Complexité de construction | Compacité / Encombrement / intégration | Poids ajouté | Bruit (nuisances acoustiques) | Vibrations transmises | Sécurité des utilisateurs | Facilité de maintenance | Durabilité des matériaux | Résistance poussière/humidité (IP) | Complexité de commande | Disponibilité des composants | Temps & risque de prototypage (TRL) | Modularité / évolutivité | Démontabilité / transport | Impact sur le centre de gravité | Aptitude/Capacité tout terrain | Somme verticale | (copy) Somme horizontal | Somme totale | Score normalizé | Critère | De: Critère | Brève description
Efficacité énergétique du vol | 0 |  |  |  |  |  |  |  |  |  |  |  |  |  |  |  |  |  |  | 0 | 0 | 0 | 0.500 | Efficacité énergétique du vol | Flug-/Energieeffizienz | Performance globale en vol (portance, traînée, endurance)
Robustesse en collision | -1 | 0 |  |  |  |  |  |  |  |  |  |  |  |  |  |  |  |  |  | -1 | 15 | 16 | 1.000 | Robustesse en collision | Kollisionsrobustheit | Résistance en cas de contact/accrochage
Coût | 1 | 1 | 0 |  |  |  |  |  |  |  |  |  |  |  |  |  |  |  |  | 2 | -6 | -8 | 0.250 | Coût | Kosten | Prix des composants et fabrication
Complexité de construction | 1 | 1 | -1 | 0 |  |  |  |  |  |  |  |  |  |  |  |  |  |  |  | 1 | -5 | -6 | 0.312 | Complexité de construction | Konstruktionskomplexität | Difficulté d’usinage/assemblage
Compacité / Encombrement / intégration | -1 | 1 | -1 | -1 | 0 |  |  |  |  |  |  |  |  |  |  |  |  |  |  | -2 | 4 | 6 | 0.688 | Compacité / Encombrement / intégration | Kompaktheit | Taille minimale possible/ Intégration dans l’enveloppe
Poids ajouté | -1 | 1 | -1 | 1 | 1 | 0 |  |  |  |  |  |  |  |  |  |  |  |  |  | 1 | -3 | -4 | 0.375 | Poids ajouté | Zusätzliches Gewicht | Masse supplémentaire intégrée au dirigeable
Bruit (nuisances acoustiques) | -1 | 1 | -1 | 1 | 1 | 1 | 0 |  |  |  |  |  |  |  |  |  |  |  |  | 2 | -12 | -14 | 0.062 | Bruit (nuisances acoustiques) | Geräuschentwicklung (akustische Störungen) | Niveau sonore en fonctionnement
Vibrations transmises | 1 | 1 | 1 | -1 | 1 | -1 | -1 | 0 |  |  |  |  |  |  |  |  |  |  |  | 1 | -1 | -2 | 0.438 | Vibrations transmises | Übertragene Vibrationen | Effets sur structure et capteurs
Sécurité des utilisateurs | -1 | -1 | -1 | -1 | -1 | -1 | -1 | -1 | 0 |  |  |  |  |  |  |  |  |  |  | -8 | 6 | 14 | 0.938 | Sécurité des utilisateurs | Benutzersicherheit | Risques d’aspiration, arêtes, contact
Facilité de maintenance | -1 | 1 | -1 | -1 | -1 | -1 | -1 | -1 | -1 | 0 |  |  |  |  |  |  |  |  |  | -7 | 7 | 14 | 0.938 | Facilité de maintenance | Wartungsfreundlichkeit | Accès, temps de remplacement
Durabilité des matériaux | -1 | 1 | -1 | -1 | -1 | -1 | -1 | -1 | -1 | -1 | 0 |  |  |  |  |  |  |  |  | -8 | -2 | 6 | 0.688 | Durabilité des matériaux | Materialhaltbarkeit | Usure, Cupe, …
Résistance poussière/humidité (IP) | 1 | 1 | 1 | 1 | 1 | 1 | -1 | 1 | 1 | 1 | 1 | 0 |  |  |  |  |  |  |  | 9 | -7 | -16 | 0.000 | Résistance poussière/humidité (IP) | Staub- / Feuchtigkeitsbeständigkeit (IP) | Robustesse environnementale
Complexité de commande | 1 | 1 | 1 | 1 | -1 | -1 | -1 | -1 | 1 | 1 | -1 | -1 | 0 |  |  |  |  |  |  | 0 | 4 | 4 | 0.625 | Complexité de commande | Steuerungskomplexität | Besoin en capteurs/algorithmes
Disponibilité des composants | 1 | 1 | -1 | -1 | -1 | -1 | -1 | 1 | 1 | 1 | -1 | -1 | 1 | 0 |  |  |  |  |  | -1 | 3 | 4 | 0.625 | Disponibilité des composants | Verfügbarkeit der Komponenten | Délais/chaîne d’approvisionnement
Temps & risque de prototypage (TRL) | 1 | 1 | -1 | -1 | 1 | -1 | -1 | -1 | 1 | 1 | -1 | -1 | -1 | 1 | 0 |  |  |  |  | -2 | 4 | 6 | 0.688 | Temps & risque de prototypage (TRL) | Zeit & Risiko beim Prototyping (TRL) | Maturité technologique
Modularité / évolutivité | -1 | 1 | 1 | 1 | 1 | 1 | -1 | 1 | 1 | 1 | 1 | -1 | 1 | 1 | 1 | 0 |  |  |  | 9 | -1 | -10 | 0.188 | Modularité / évolutivité | Modularität / Erweiterbarkeit | Possibilité d’améliorations futures
Démontabilité / transport | -1 | 1 | -1 | -1 | 1 | 1 | -1 | 1 | 1 | 1 | 1 | -1 | 1 | 1 | 1 | 1 | 0 |  |  | 6 | -2 | -8 | 0.250 | Démontabilité / transport | Demontierbarkeit / Transport | Montage/démontage, stockage
Impact sur le centre de gravité | 1 | 1 | -1 | -1 | 1 | -1 | -1 | 1 | 1 | 1 | -1 | -1 | 1 | 1 | 1 | -1 | -1 | 0 |  | 1 | -1 | -2 | 0.438 | Impact sur le centre de gravité | Einfluss auf den Schwerpunkt | Effet sur la répartition des masses
Aptitude/Capacité tout terrain | 1 | 1 | 1 | -1 | 1 | 1 | -1 | -1 | 1 | 1 | -1 | -1 | 1 | -1 | 1 | -1 | -1 | -1 | 0 | 0 | 0 | 0 | 0.500 | Aptitude/Capacité tout terrain | Geländefähigkeit | Réaction aux perturbations telles que joints, bosses, …
 | 0 | 15 | -6 | -5 | 4 | -3 | -12 | -1 | 6 | 7 | -2 | -7 | 4 | 3 | 4 | -1 | -2 | -1 | 0
 |  |  |  |  |  |  |  |  |  |  |  |  |  |  |  |  |  |  |  |  |  | Copy manually, then sort!!!
 |  |  |  |  |  |  |  |  |  |  |  |  |  |  |  |  |  |  |  |  |  | Somme totale | Score normalizé | Critère | De: Critère | Brève description
 |  |  |  |  |  |  |  |  |  |  |  |  |  |  |  |  |  |  |  |  |  | 16 | 1.000 | Robustesse en collision | Kollisionsrobustheit | Résistance en cas de contact/accrochage
 |  |  |  |  |  |  |  |  |  |  |  |  |  |  |  |  |  |  |  |  |  | 14 | 0.938 | Sécurité des utilisateurs | Benutzersicherheit | Risques d’aspiration, arêtes, contact
 |  |  |  |  |  |  |  |  |  |  |  |  |  |  |  |  |  |  |  |  |  | 14 | 0.938 | Facilité de maintenance | Wartungsfreundlichkeit | Accès, temps de remplacement
 |  |  |  |  |  |  |  |  |  |  |  |  |  |  |  |  |  |  |  |  |  | 6 | 0.688 | Compacité / Encombrement / intégration | Kompaktheit | Taille minimale possible/ Intégration dans l’enveloppe
 |  |  |  |  |  |  |  |  |  |  |  |  |  |  |  |  |  |  |  |  |  | 6 | 0.688 | Durabilité des matériaux | Materialhaltbarkeit | Usure, Cupe, …
 |  |  |  |  |  |  |  |  |  |  |  |  |  |  |  |  |  |  |  |  |  | 6 | 0.688 | Temps & risque de prototypage (TRL) | Zeit & Risiko beim Prototyping (TRL) | Maturité technologique
 |  |  |  |  |  |  |  |  |  |  |  |  |  |  |  |  |  |  |  |  |  | 4 | 0.625 | Complexité de commande | Steuerungskomplexität | Besoin en capteurs/algorithmes
 |  |  |  |  |  |  |  |  |  |  |  |  |  |  |  |  |  |  |  |  |  | 4 | 0.625 | Disponibilité des composants | Verfügbarkeit der Komponenten | Délais/chaîne d’approvisionnement
 |  |  |  |  |  |  |  |  |  |  |  |  |  |  |  |  |  |  |  |  |  | 0 | 0.500 | Efficacité énergétique du vol | Flug-/Energieeffizienz | Performance globale en vol (portance, traînée, endurance)
 |  |  |  |  |  |  |  |  |  |  |  |  |  |  |  |  |  |  |  |  |  | 0 | 0.500 | Aptitude/Capacité tout terrain | Geländefähigkeit | Réaction aux perturbations telles que joints, bosses, …
 |  |  |  |  |  |  |  |  |  |  |  |  |  |  |  |  |  |  |  |  |  | -2 | 0.438 | Vibrations transmises | Übertragene Vibrationen | Effets sur structure et capteurs
 |  |  |  |  |  |  |  |  |  |  |  |  |  |  |  |  |  |  |  |  |  | -2 | 0.438 | Impact sur le centre de gravité | Einfluss auf den Schwerpunkt | Effet sur la répartition des masses
 |  |  |  |  |  |  |  |  |  |  |  |  |  |  |  |  |  |  |  |  |  | -4 | 0.375 | Poids ajouté | Zusätzliches Gewicht | Masse supplémentaire intégrée au dirigeable
 |  |  |  |  |  |  |  |  |  |  |  |  |  |  |  |  |  |  |  |  |  | -6 | 0.312 | Complexité de construction | Konstruktionskomplexität | Difficulté d’usinage/assemblage
 |  |  |  |  |  |  |  |  |  |  |  |  |  |  |  |  |  |  |  |  |  | -8 | 0.250 | Coût | Kosten | Prix des composants et fabrication
 |  |  |  |  |  |  |  |  |  |  |  |  |  |  |  |  |  |  |  |  |  | -8 | 0.250 | Démontabilité / transport | Demontierbarkeit / Transport | Montage/démontage, stockage
 |  |  |  |  |  |  |  |  |  |  |  |  |  |  |  |  |  |  |  |  |  | -10 | 0.188 | Modularité / évolutivité | Modularität / Erweiterbarkeit | Possibilité d’améliorations futures
 |  |  |  |  |  |  |  |  |  |  |  |  |  |  |  |  |  |  |  |  |  | -14 | 0.062 | Bruit (nuisances acoustiques) | Geräuschentwicklung (akustische Störungen) | Niveau sonore en fonctionnement
 |  |  |  |  |  |  |  |  |  |  |  |  |  |  |  |  |  |  |  |  |  | -16 | 0.000 | Résistance poussière/humidité (IP) | Staub- / Feuchtigkeitsbeständigkeit (IP) | Robustesse environnementale

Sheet: ChoixTypHovercraft
 |  | Scrore de la solution [0-10] |  |  | Score pondéré
Critère | Facteur d’importance [0–1] | Opt1: Open plenum | Opt2: Peripheral jet | Opt3: Flexible skirt | Opt1: Open plenum | Opt2: Peripheral jet | Opt3: Flexible skirt
Efficacité énergétique du vol | 0.50 | 7 | 8 | 10 | 3.5 | 4 | 5
Robustesse en collision | 1.00 | 10 | 10 | 7 | 10 | 10 | 7
Coût | 0.25 | 5 | 5 | 5 | 1.25 | 1.25 | 1.25
Complexité de construction | 0.31 | 8 | 7 | 5 | 2.5 | 2.1875 | 1.5625
Compacité / Encombrement / intégration | 0.69 | 7 | 7 | 6 | 4.8125 | 4.8125 | 4.125
Poids ajouté | 0.38 | 5 | 5 | 5 | 1.875 | 1.875 | 1.875
Bruit (nuisances acoustiques) | 0.06 | 5 | 5 | 5 | 0.3125 | 0.3125 | 0.3125
Vibrations transmises | 0.44 | 4 | 5 | 9 | 1.75 | 2.1875 | 3.9375
Sécurité des utilisateurs | 0.94 | 5 | 5 | 5 | 4.6875 | 4.6875 | 4.6875
Facilité de maintenance | 0.94 | 10 | 8 | 6 | 9.375 | 7.5 | 5.625
Durabilité des matériaux | 0.69 | 7 | 6 | 5 | 4.8125 | 4.125 | 3.4375
Résistance poussière/humidité (IP) | 0.00 | 8 | 8 | 5 | 0 | 0 | 0
Complexité de commande | 0.62 | 5 | 5 | 5 | 3.125 | 3.125 | 3.125
Disponibilité des composants | 0.62 | 5 | 5 | 5 | 3.125 | 3.125 | 3.125
Temps & risque de prototypage (TRL) | 0.69 | 6 | 6 | 5 | 4.125 | 4.125 | 3.4375
Modularité / évolutivité | 0.19 | 6 | 5 | 5 | 1.125 | 0.9375 | 0.9375
Démontabilité / transport | 0.25 | 6 | 6 | 5 | 1.5 | 1.5 | 1.25
Impact sur le centre de gravité | 0.44 | 6 | 5 | 4 | 2.625 | 2.1875 | 1.75
Aptitude/Capacité tout terrain | 0.50 | 4 | 6 | 8 | 2 | 3 | 4
 |  |  |  |  | 0 | 0 | 0
 |  |  |  |  | 0 | 0 | 0
 |  |  |  | Scores moyennes: | 3.4722 | 3.3854 | 3.1354

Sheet: MatriceDesSolutions
Prof. Piat Construction et gestion de produits SUPMICROTECH-ENSMM |  |  | Matrice des Solutions pour µ-verCraft | Commande: XXX Numéro de commande: / Semestre d'hiver 2025/26
Données organis. |  | Données du processus | Éléments problématiques | Composantes de solution
Nb. | Nom | Type |  | S1 | S2 | S3 | S4
E1 |  |  | Créer des coussins d'air | 1 hélice | 2 hélices tournant en sens inverse
E2 |  |  | Sceller les coussins d'air | Open plenum | Peripheral jet | Flexible skirt
E3 |  |  | Mesurer l'abaissement de l'air | ne pas mesurer | Distance IR | Distance TOF
E4 |  |  | Générer une poussée | 1 hélice | 2 hélices tournant en sens inverse
E5 |  |  | Freiner la poussée | ne pas freiner | Faire tourner l'hélice à l'envers
E6 |  |  | Stabilisation de la rotation autour de l'axe z | Servo + Airfoil | Poussée différentielle -> 2 Hélice | Couple des moteurs à coussin d'air
E7 |  |  | Télécommande | BT | WiFi
E8 |  |  | Approvisionnement en énergie | 1S | 2S
E9 |  |  | Unité de contrôle | ESP32 | Arduino
E10 |  |  | Positionnement dans l'espace | Capteur IR | IMU | Capteur flux optique
E11 |  |  | Vitesse dans l'espace | 3 Capteurs IR | Intégration données IMU | 2 capteurs flux optique
E12
E13
E14
E15
E16
Types d'exigences: O/N-Oui/Non; E-Exigence; S-Souhait
Remplace l'édition: / de: / Version: / |  |  |  | Édition actuelle: de: 17/09/2025 Version: 01
Fichier: XXX.xlsx Registre: muVerCraft |  |  | Page 1 sur 1 | Date d'enregistrement: 17/09/2025

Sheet: BOM
 |  |  |  |  |  |  |  |  |  |  |  |  |  | Name | link
 |  |  |  |  |  |  |  |  |  |  |  |  |  | IR Sens | https://www.pololu.com/product/4241
 | nb. Pièces/Hovercraft | nb. Pièces/Command | Option1 |  | Option2 |  | Option3 |  |  | approx. Weight sum |  | cost/piece | total cost
ESP32 | 1 | 1 | Carte XIAO ESP32S3 113991114 - Gotronic (https://www.gotronic.fr/art-carte-xiao-esp32s3-36954.htm) | GoTronic |  |  |  |  |  | 3.3 | g | 8.60 € | 8.60 €
ESC 4in1, 16mm | 1 | 1 | ESC 4en1 Goku BLS 35A V3 4S | Flywoo (https://www.lacameraembarquee.fr/esc-fpv/18795-esc-4en1-flywoo-goku-bls-35a-v3-4s.html) | CaméraEmbarquée |  |  |  |  |  | 3.6 | g | 45.90 € | 45.90 €
Capteur IR | 3 | 3 | Suiveur de ligne 4241 - Gotronic (https://www.gotronic.fr/art-suiveur-de-ligne-4241-31140.htm) | GoTronic |  |  |  |  |  | 1.05 | g | 2.90 € | 8.70 €
IMU (Module 10 DoF SEN0140) | 1 | 1 | https://www.gotronic.fr/art-module-10-dof-sen0140-19698.htm | GoTronic |  |  |  |  |  | 1.6 | g | 5.80 € | 5.80 €
7,4V->5V regulateur | 1 | 1 | Régulateur de tension BEC V2.0 5V/12V 2A Flywoo (https://www.lacameraembarquee.fr/pdb-bec-led-fpv/14437-bec-v20-flywoo-5v12v-2a.html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) | CaméraEmbarquée |  |  |  |  |  | 2 | g | 9.90 € | 9.90 €
moteur | 4 | 5 | Flywoo | Moteur Robo 1003 14800Kv (https://www.lacameraembarquee.fr/moteurs-fpv/15628-moteur-flywoo-robo-1003-14800kv.html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..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) | CaméraEmbarquée | Moteur M2 1002 21000Kv | Sub250 (https://www.lacameraembarquee.fr/moteurs-fpv/18115-moteur-sub250-m2-1002-21000kv.html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) | CaméraEmbarquée | Moteur Brushless GTS V3 1002 - 14000KV - Rcinpower - Drone-FPV-Racer.com (https://www.drone-fpv-racer.com/moteur-brushless-gts-v3-1002-14000kv-rcinpower-9807.html) | DroneFPVRacer |  | 17.6 | g | 14.90 € | 74.50 €
helices (d=35mm) | 1 | 2 | Hélices 35mms tripales 1309 (1.3x0.96x3) shaft 1.5mm | Gemfan (https://www.lacameraembarquee.fr/helices-fpv/18886-helices-gemfan-35mms-tripales-1309-13x096x3-shaft-15mm-6936572228471.html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..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) | CaméraEmbarquée |  |  | Hélices HQ Ultralight 1.4x1.1x3 (2CW+2CCW) - 1.5mm shaft - HQProp - Drone-FPV-Racer.com (https://www.drone-fpv-racer.com/helices-hq-ultralight-14x11x3-2cw2ccw-15mm-shaft-hqprop-14120.html) | DroneFPVRacer |  | 3.6 | g | 2.90 € | 5.80 €
batterie (2s ~300mAh-550mAh) | 1x pack de 3 | 1 | Pack de 3 batteries LiPo HV 2S 450mAh 70C | CNHL (https://www.lacameraembarquee.fr/batteries-fpv/15924-pack-de-3-batteries-lipo-cnhl-hv-2s-450mah-70c.html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..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) | CaméraEmbarquée | BetaFPV | Lot de 2 batteries LiHV LAVA 2S 450mAh 75C (https://www.lacameraembarquee.fr/batteries-fpv/16179-pack-de-2-batteries-lihv-betafpv-lava-2s-450mah-75c-0725764458675.html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..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) | CaméraEmbarquée | Batterie LiPo 2S 300mAh 75C (XT30) | Bonka (https://www.lacameraembarquee.fr/batteries-fpv/18528-batterie-lipo-bonka-2s-300mah-75c-xt30.html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) | CaméraEmbarquée |  | 31 | ~32g (18g-40g) | 16.90 € | 16.90 €
Bois de 3mm (chassis) | 1 | 1 | Contreplaqué en peuplier Pichler Modellbau C8634 (L x l x H) 600 x 300 x 3.0 mm 2 pc(s) - Conrad Electronic France (https://www.conrad.fr/fr/p/contreplaque-en-peuplier-pichler-modellbau-c8634-l-x-l-x-h-600-x-300-x-3-0-mm-2-pc-s-1612054.html) | Conrad | Contreplaqué en peuplier Pichler Modellbau C8635 (L x l x H) 900 x 300 x 3.0 mm 2 pc(s) - Conrad Electronic France (https://www.conrad.fr/fr/p/contreplaque-en-peuplier-pichler-modellbau-c8635-l-x-l-x-h-900-x-300-x-3-0-mm-2-pc-s-1612055.html) | Conrad |  |  |  | 17.2 | g (CAO) | 10.99 € | 10.99 €
Mousse 10mm (Polystyrol) | 2+1 | 6 | https://www.leroymerlin.fr/produits/1-plaque-isolant-en-polystyrene-extrude-depron-l-1-m-x-l-1-m-x-ep-9-mm-1m2-69104756.html | Nous même |  |  |  |  |  | 2.8 | g (CAO) | 0.00 € | 0.00 €
Velcro / Bande auto-agrippante | 1 | 1 | Quadrios 25CA526 Bande auto-agrippante à coller partie velours et partie agrippante noir Marchandise vendue au mètre - Conrad Electronic France (https://www.conrad.fr/fr/p/quadrios-25ca526-bande-auto-agrippante-a-coller-partie-velours-et-partie-agrippante-noir-marchandise-vendue-au-metre-3450029.html) | Conrad |  |  |  |  |  | 2 | g | 1.99 € | 1.99 €
resistance 100k Ohm | 1 | 3 | - | ENSMM | 1M Ω |  | 1:2 grand resistance |  |  | 1 | ~g |  | 0.00 €
resistance 220k Ohm | 1 | 3 | - | ENSMM | 2M Ω |  | 1:2 grand resistance |  |  | 1 | ~g |  | 0.00 €
Adaptateur pour charger XT60/XT30 | 1 | 2 | Adaptateur XT30 mâle vers XT60 femelle | LemonFPV (https://www.lacameraembarquee.fr/cables-adaptateurs-connecteurs-fpv/15039-adaptateur-xt30-male-vers-xt60-femelle-lemonfpv.html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..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) | CaméraEmbarquée | Adaptateur XT30 mâle vers XT60 femelle avec câble 10cm | LemonFPV (https://www.lacameraembarquee.fr/cables-adaptateurs-connecteurs-fpv/15036-adaptateur-xt30-male-vers-xt60-femelle-avec-cable-10cm-lemonfpv.html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) | CaméraEmbarquée |  |  |  | - | - | 1.90 € | 3.80 €
cables | 1x noir | 1 | Câble silicone 28 AWG 1 mètre LemonFPV (https://www.lacameraembarquee.fr/cables-adaptateurs-connecteurs-fpv/14505-6312-cable-silicone-lemonfpv-28-awg-1-metre.html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) | CaméraEmbarquée |  |  |  |  |  | 2 | g en totale | 1.30 € | 1.30 €
cables | 1x rouge | 1 | Câble silicone 28 AWG 1 mètre LemonFPV (https://www.lacameraembarquee.fr/cables-adaptateurs-connecteurs-fpv/14505-6314-cable-silicone-lemonfpv-28-awg-1-metre.html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) | CaméraEmbarquée |  |  |  |  |  | - | - | 1.30 € | 1.30 €
cables | 1x jaune | 1 | Câble silicone 28 AWG 1 mètre LemonFPV (https://www.lacameraembarquee.fr/cables-adaptateurs-connecteurs-fpv/14505-6313-cable-silicone-lemonfpv-28-awg-1-metre.html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) | CaméraEmbarquée |  |  |  |  |  | - | - | 1.30 € | 1.30 €
cables | 1x blanc | 1 | Câble silicone 28 AWG 1 mètre LemonFPV (https://www.lacameraembarquee.fr/cables-adaptateurs-connecteurs-fpv/14505-6315-cable-silicone-lemonfpv-28-awg-1-metre.html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) | CaméraEmbarquée |  |  |  |  |  | - | - | 1.30 € | 1.30 €
 |  |  |  |  |  |  |  |  | SOMME: | 89.75 | g |  | 198.08 €

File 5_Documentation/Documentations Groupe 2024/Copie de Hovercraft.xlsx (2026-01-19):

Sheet: Feuille 1
Fournisseur :
Gotronic URL (https://www.moodle.ens2m.fr/mod/url/view.php?id=24650)
Conrad URL (https://www.moodle.ens2m.fr/mod/url/view.php?id=24649)
Generation Robots URL (https://www.moodle.ens2m.fr/mod/url/view.php?id=24884)
Misumi URL (https://www.moodle.ens2m.fr/mod/url/view.php?id=24646)
Radiospares URL (https://www.moodle.ens2m.fr/mod/url/view.php?id=24647)
Farnell URL (https://www.moodle.ens2m.fr/mod/url/view.php?id=24648)
Digikey URL (https://www.moodle.ens2m.fr/mod/url/view.php?id=24652)
Mouser URL (https://www.moodle.ens2m.fr/mod/url/view.php?id=24653)
Microprocessor (Boult) URL (https://www.moodle.ens2m.fr/mod/url/view.php?id=24654)
Reboul (Besançon) URL (https://www.moodle.ens2m.fr/mod/url/view.php?id=24655)
Carbonetube URL (https://www.moodle.ens2m.fr/mod/url/view.php?id=24656)
Trotec
FRANCOIS MARIONNET (INGE ENSMM ELEC)

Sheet: Nomenclature (commande)
Nom | Nombre | Prix (u) | Prix (tot) | État | Réception | Description | Commentaire | Lien | Fournisseur | Doc | Poids (u) | Poids (tot)
Moteur SmooX 1507 Plus - 3800KV | 4 | 19.9 | 79.6 | Validé | Oui | 3800KV | Fonctionne avec une batterie 4S | Lien (https://www.drone-fpv-racer.com/moteur-smoox-1507-plus-3800kv-rcinpower-9822.html) | Rcinpower |  | 16.7 | 66.8
GEMFAN 3052 - Tripales - Polycarbonate - 4pcs | 2 | 2.9 | 5.8 | Validé | Oui | Shaft M5, diamètre 3 pouces | x4 per unit | Lien (https://www.drone-fpv-racer.com/gemfan-3052-tripales-polycarbonate-4pcs-1977.html) | Gemfan |  | 2 | 4
ESCs (Régulateur brushless) | 4 | 27.99 | 111.96 | Validé | Oui | Pichler XQ - Charge admissible (max.): 50 A Continue 40 A |  | Lien (https://www.conrad.fr/fr/p/pichler-pulsar-b-40-regulateur-de-vitesse-brushless-de-voiture-charge-admissible-max-50-a-3204132.html) | Conrad Electronic/ Pichler |  | 45 | 180
Servomoteur analogique | 2 | 9.49 | 18.98 | Validé | Oui | (L x l x H) 23 x 12 x 24 mm, Tension de fonctionnement 4.8 - 6 V |  | Lien (https://www.conrad.fr/fr/p/reely-mini-servomoteur-analogique-materiau-entrainement-plastique-systeme-de-connecteur-jr-2148502.html) | Conrad Electronic/ Reely |  | 8 | 16
Arduino Nano 33 BLE Rev2 ABX00072 | 2 | 35.2 | 70.4 | Validé | Oui | Carte de développement Arduino Nano 33 BLE Rev2 basée sur un microcontrôleur Cortex-M4 avec interface Bluetooth 5 combinée à une unité de mesure inertielle | Besoin d'un régulateur de tension pour l'alimentation | Lien (https://www.gotronic.fr/art-arduino-nano-33-ble-rev2-abx00072-38727.htm) | Gotronic / Arduino |  | 5 | 10
Batterie Lipo Tattu 4S 1300mAh 100C | 2 | 24.99 | 49.98 | Validé | Oui | Dimension: (L x l x H) 73 x 35 x 28 mm |  | Lien (https://www.conrad.fr/fr/p/tattu-pack-de-batterie-lipo-14-8-v-1300-mah-nombre-de-cellules-4-100-c-softcase-xt60-1892614.html) | Tattu |  | 149 | 298
Régulateur de tension 3,3V | 2 | 4.6 | 9.2 | Validé | Oui |  | L'arduino ne prend que du 3,3V et l'ESC ne renvoie que 5-6V (Il s'avert que l'Arduino à son propre step down donc inutile) | Lien (https://www.mouser.fr/ProductDetail/Adafruit/2745?qs=F12%252BZJI6bgq%252BRTrDjijiPw%3D%3D) | Mooser | https://cdn-shop.adafruit.com/product-files/2745/P2745_Datasheet.pdf | 2 | 4
Toile en polyester (pour la jupe) | 1 | 8 | 8 | Validé | Oui | Doit être résistant et imperméable idéalement ( K-way/sac poubelle potentielle) | (a nos frais) |  |  |  | 10 | 10
Capteur IR | 2 | 4.4 | 8.8 | Validé | Oui | Module suiveur de ligne Grove 101020172 |  | Lien (https://www.gotronic.fr/art-module-suiveur-de-ligne-grove-101020172-18974.htm) | Gotronic | https://wiki.seeedstudio.com/Grove-Line_Finder/ | 8 | 16
 |  |  |  |  |  |  |  |  |  | https://www.seeedstudio.com/Grove-Line-Finder-v1-1.html
 |  |  |  |  |  |  |  |  |  | https://www.instructables.com/Make-a-mini-toy-car-with-Arduino/
 |  |  | Prix Total : | 283.12 | (sans frais de livraison)

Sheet: Nomenclature (CAO)
Nom | Nombre | État | Matériau | Poids | Description | Commentaire
prt_lift_struct.prt | 1 | En conception
prt_lower_bati.prt | 1 | En conception
prt_rudder.prt | 2 | En conception
prt_rudders_link.prt | 1 | En conception
prt_skirt_ring.prt | 1 | En conception
prt_thrust_struct.prt | 1 | En conception
prt_upper_bati.prt | 1 | En conception

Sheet: CDCF
Fonctions | Énoncé de la fonction | Critères d'appréciation | Niveaux d'exigence
FP1 | Se déplacer de manière autonome | Précision des déplacements | < 5 cm d'erreur par rapport à la trajectoire cible
FP2 | Éviter les obstacles | Capacité à détecter et contourner les obstacles | Obstacle détecté à > 10 cm de distance
FP3 | Détecter une ligne blanche au sol | Capacité à suivre les lignes et à se relocaliser | Distinguer une bande de 2 cm de largeur à une distance de 5 cm
FC1 | Être écologique | Consommation d'énergie réduite | Batterie rechargeable, durée de vie > 1 heure
FC2 | Coût de production abordable | Coût de fabrication par unité | < 250€
FC3 | Être esthétique | Design et finitions | Compact, design aérodynamique
FC4 | Respecter les normes de sécurité | Sécurité des composants et utilisateurs | Composants non coupants, tensions < 24V
FC5 | Facile à programmer et contrôler | Temps nécessaire à la configuration | Moins de 30 minutes pour la configuration initiale
FC6 | Résister à l’usure et à l’humidité | Robustesse des matériaux | Matériaux imperméables et résistants aux chocs
FC7 | Avoir une documentation complète | Clarté des instructions et plans | Documentation technique détaillée et schémas CAO fournis
FC8 | Réalisation faisable par des étudiants | Complexité des tâches | Niveau adapté pour des débutants en robotique et mécatronique
FC9 | Avoir un poids réduit | Maniabilité et transportabilité | P1 : Poids total < 750 g P2 : Poids total < 500g
FC10 | Loi de commande | Effectuer plusieurs simulation | Loi de commande correct

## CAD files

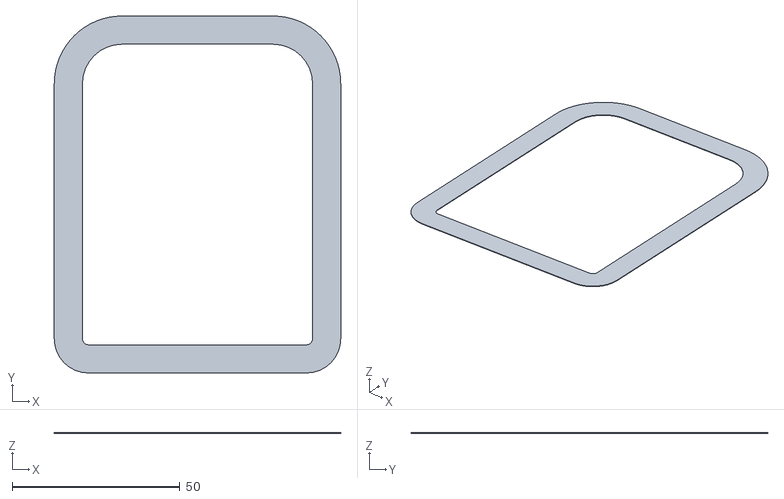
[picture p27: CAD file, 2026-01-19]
2_Mecanique/Hovercraft_PLA_GlideRing_v1.stl
85.4 x 106.4 x 0.2

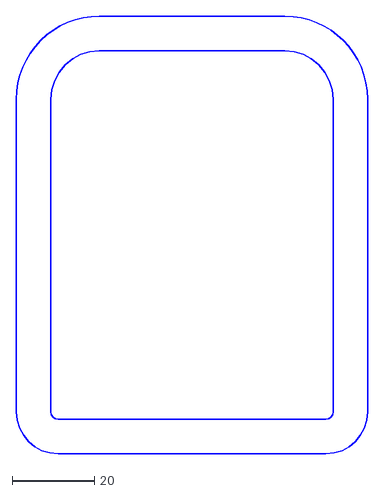
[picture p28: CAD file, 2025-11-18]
2_Mecanique/svg_laser/b04_foam_ring_laser.dxf
85.4 x 106.4

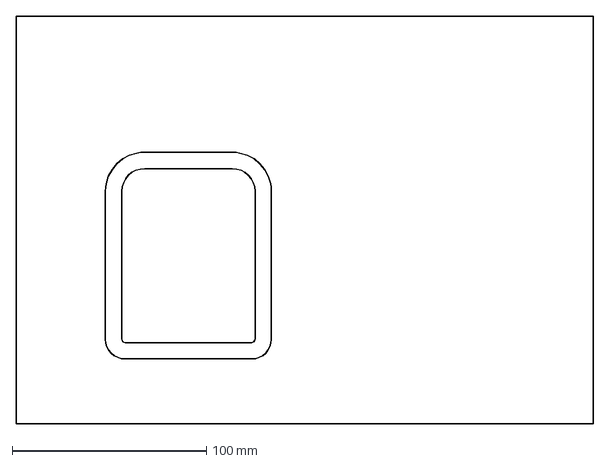
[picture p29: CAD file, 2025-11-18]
2_Mecanique/v1_0/b04_foam_ring_laser.dxf
297.0 x 210.0 mm

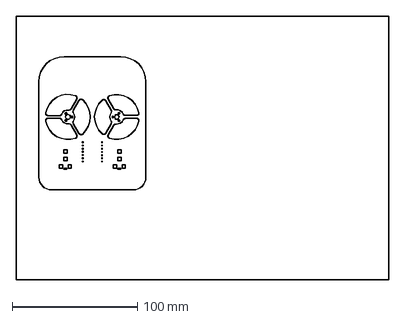
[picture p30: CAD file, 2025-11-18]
2_Mecanique/svg_laser/b01_top_plate_laser.dxf
297.0 x 210.0 mm

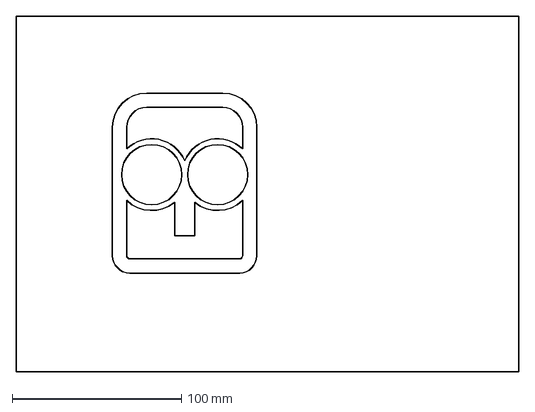
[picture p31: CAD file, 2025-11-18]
2_Mecanique/v1_0/b02_foam_duct_laser.dxf
297.0 x 210.0 mm

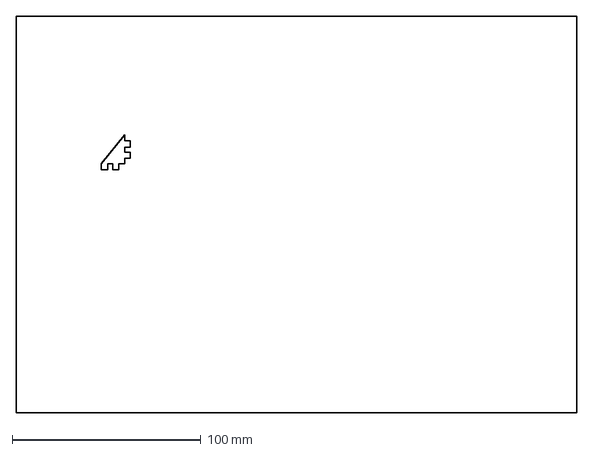
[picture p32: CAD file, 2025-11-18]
2_Mecanique/svg_laser/holder_laser.dxf
297.0 x 210.0 mm

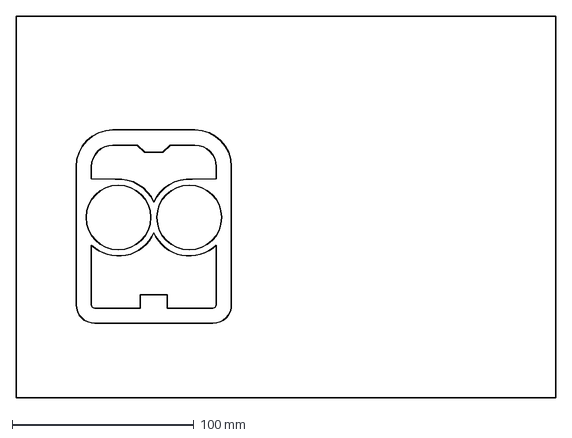
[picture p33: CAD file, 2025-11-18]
2_Mecanique/v1_0/b03_foam_duct_laser.dxf
297.0 x 210.0 mm

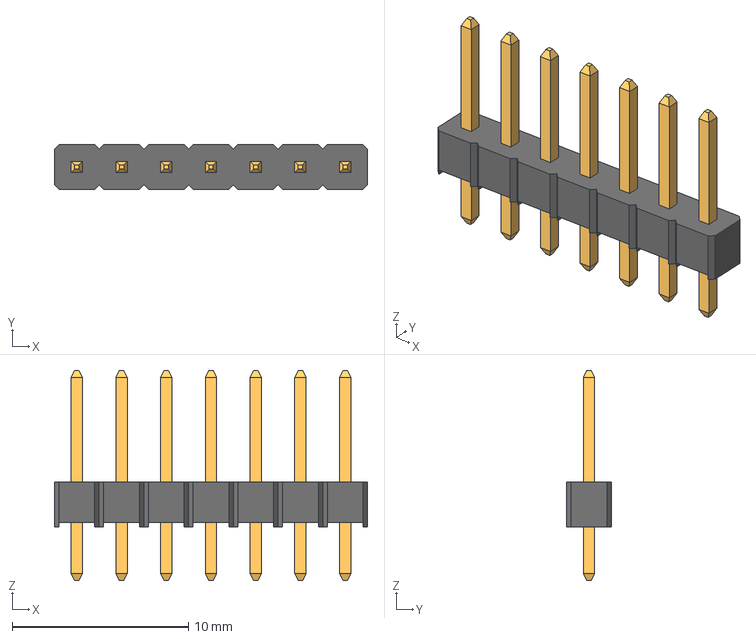
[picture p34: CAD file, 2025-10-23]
2_Mecanique/v1_0/7-Pin Header - Male - 2.54mm.step
17.8 x 2.54 x 11.9 mm

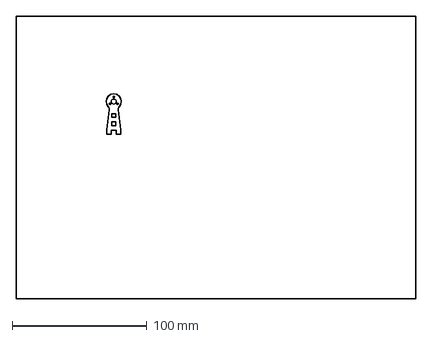
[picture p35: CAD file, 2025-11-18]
2_Mecanique/svg_laser/riser_laser.dxf
297.0 x 210.0 mm

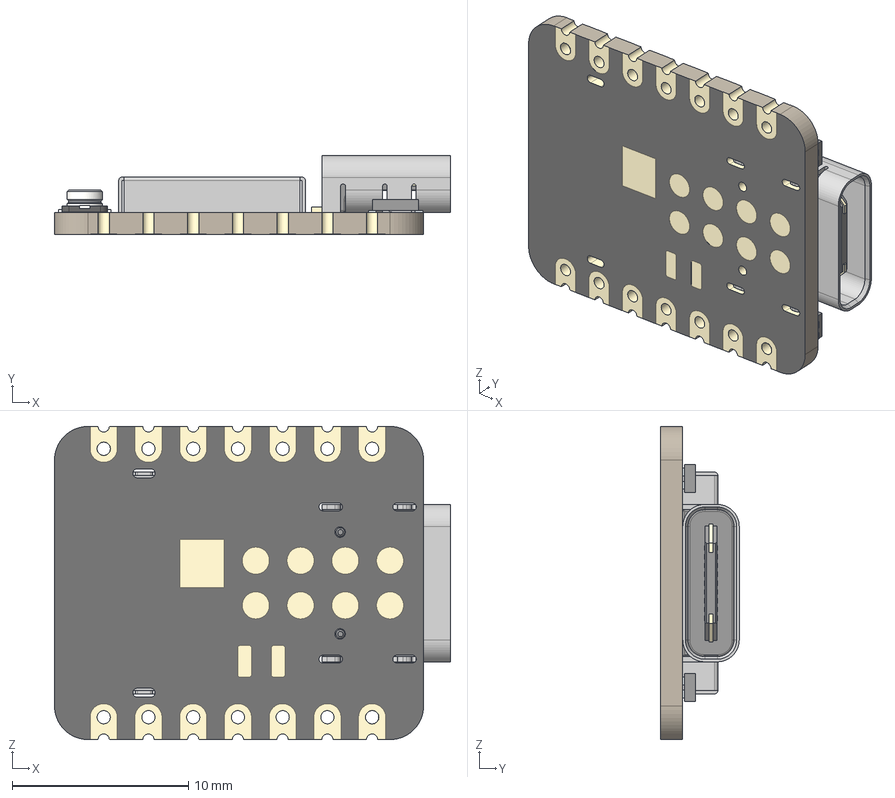
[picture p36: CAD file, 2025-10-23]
2_Mecanique/v1_0/XIAO-ESP32S3 v2.step
22.5 x 4.46 x 17.8 mm
BOSS-EXTRUDE14_8_
BOSS-EXTRUDE7_4_
BOSS-EXTRUDE7_3_
BOSS-EXTRUDE14_4_
BOSS-EXTRUDE14_2_
BOSS-EXTRUDE14_11_
BOSS-EXTRUDE7_7_
BOSS-EXTRUDE14_9_
BOSS-EXTRUDE14_3_
BOSS-EXTRUDE14_7_
MIRROR2
BOSS-EXTRUDE14_5_
BOSS-EXTRUDE14_12_
BOSS-EXTRUDE7_8_
BOSS-EXTRUDE7_1_
BOSS-EXTRUDE14_10_
BOSS-EXTRUDE7_9_
BOSS-EXTRUDE14_6_
BOSS-EXTRUDE14_1_
BOSS-EXTRUDE7_6_
BOSS-EXTRUDE7_2_
CUT-EXTRUDE5
BOSS-EXTRUDE7_5_
Shield
Pins x 2
U.FL-R-SMT-1_10_ v1

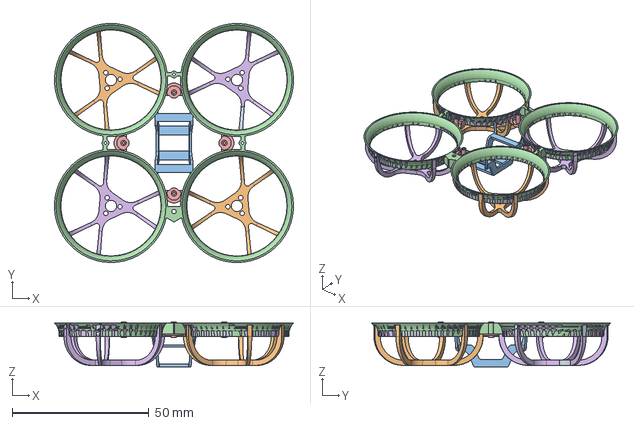
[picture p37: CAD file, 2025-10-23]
2_Mecanique/v1_0/BetaFPV Meteor65 Pro Frame v2.step
87.2 x 87.3 x 16.3 mm
Partitioned BetaFPV Meteor 65 Pro Frame
BetaFPV Meteor 65 Pro Frame

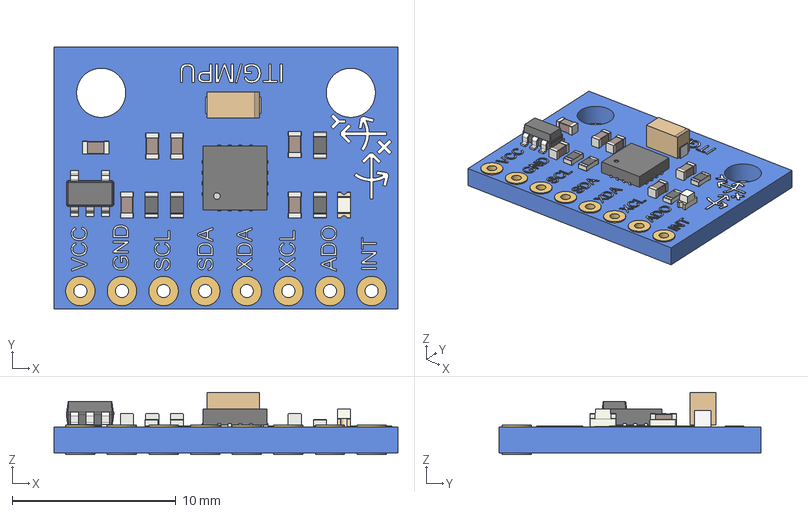
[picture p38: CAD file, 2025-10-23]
2_Mecanique/v1_0/MPU6050 Accelerometer.step
21.0 x 16.0 x 3.80 mm
PCB
trou1
trou002
trou003
trou004
trou005
trou006
trou007
trou008
Text_X
Symb_Y
Symb_X
Text_Y
Text_VCC
Text_GND
Text_SCL
Text_SDA
Text_XDA
Text_XCL
Text_ADO
Text_INT
R_0603_1608Metric
R_0603_1608Metric001
R_0603_1608Metric002
R_0603_1608Metric003
C_0603_1608Metric
C_0603_1608Metric001
C_0603_1608Metric002
C_0603_1608Metric003
Corps002
C_0603_1608Metric004
C_0603_1608Metric005
LED_0603_1608Metric_Castellated
QFN_16_1EP_4x4mm_P065mm_EP21x21mm
Text_ITGMPU
SOT_23_5
Corps001

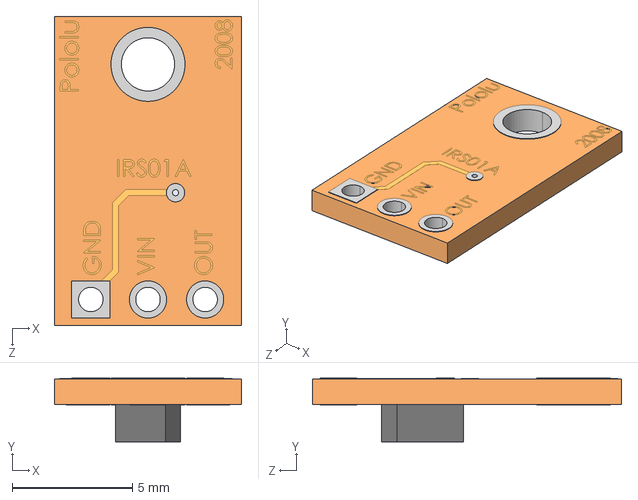
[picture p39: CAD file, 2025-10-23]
2_Mecanique/v1_0/Pololu QTR Sensor.STEP
7.77 x 2.64 x 12.8 mm

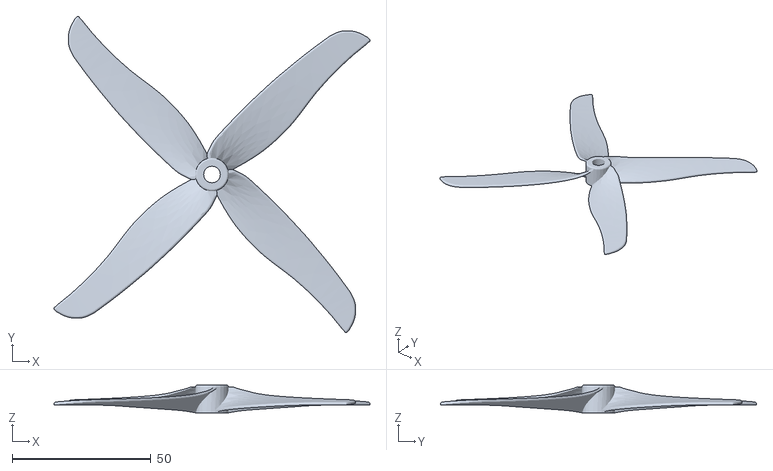
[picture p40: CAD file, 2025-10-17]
2_Mecanique/v1_0/6_Inch_Prop_6035_V2_4_Blade.stl
113.8 x 113.8 x 10.0

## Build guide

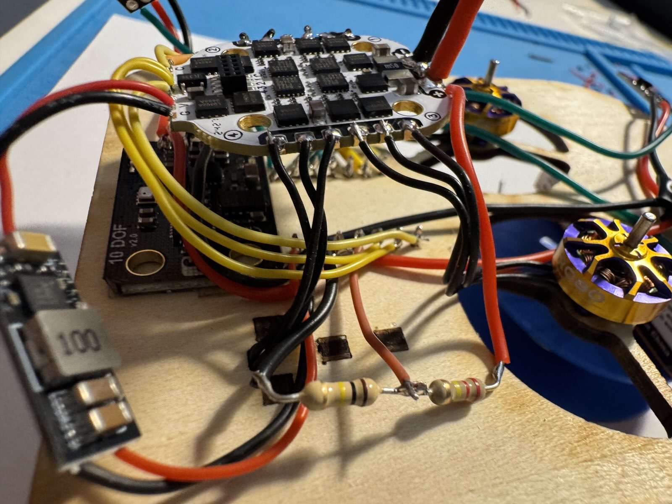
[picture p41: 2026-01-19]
1_Electronique/Assemblage/11.jpg

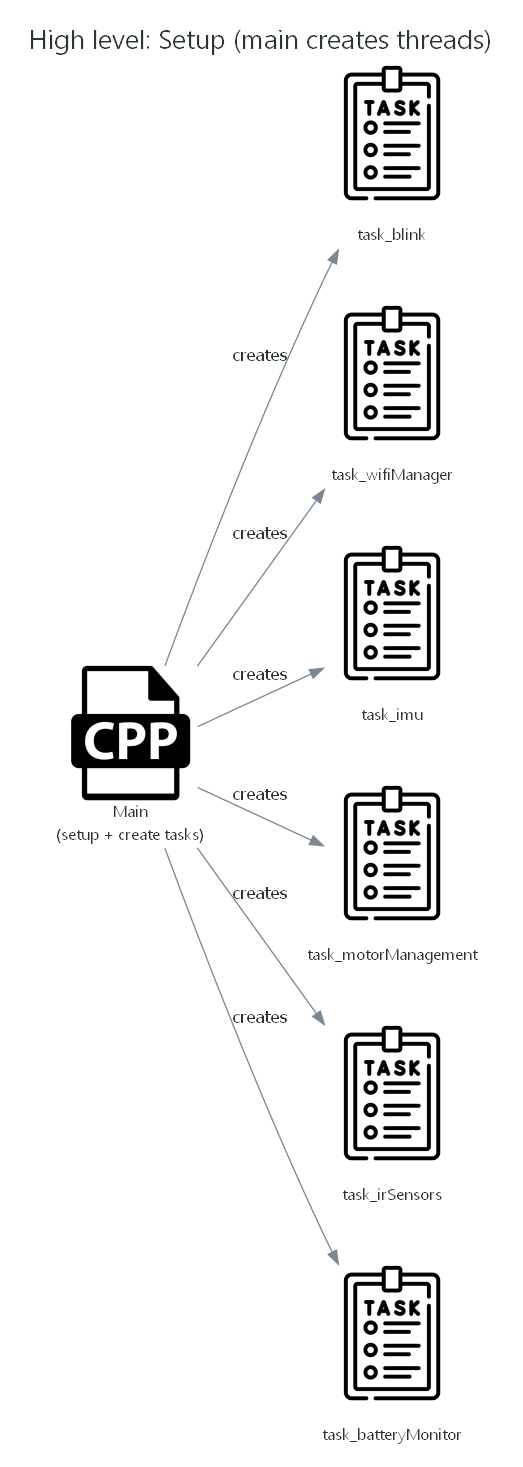
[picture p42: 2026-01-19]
3_Software/Firmware/projectStructure_Diagrams/high_level_setup.png

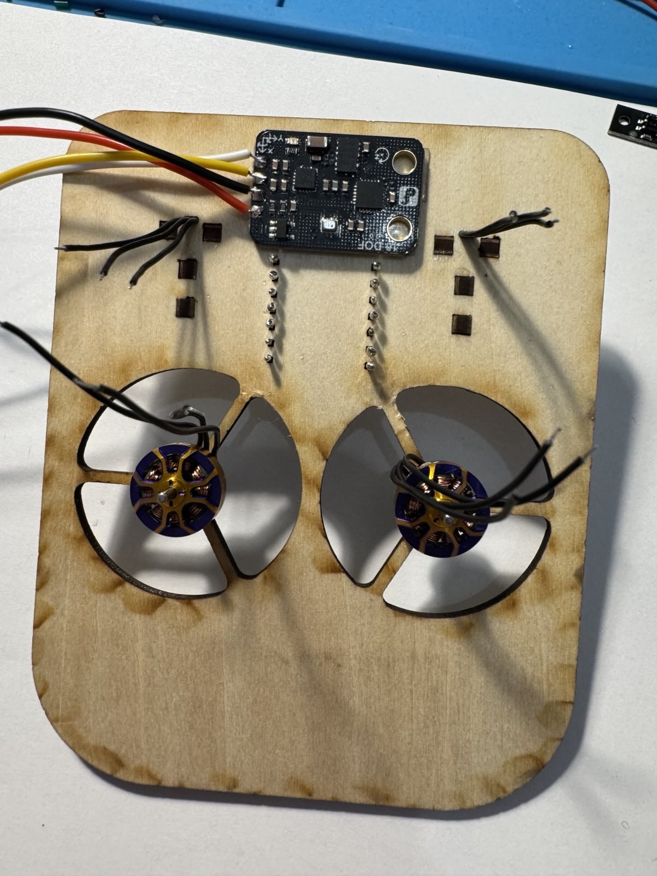
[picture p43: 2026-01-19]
1_Electronique/Assemblage/6.jpg

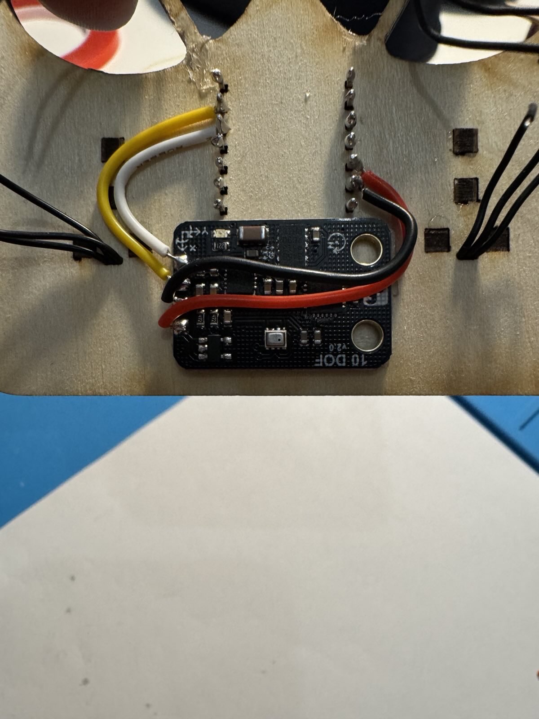
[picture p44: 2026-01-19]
1_Electronique/Assemblage/8.jpg

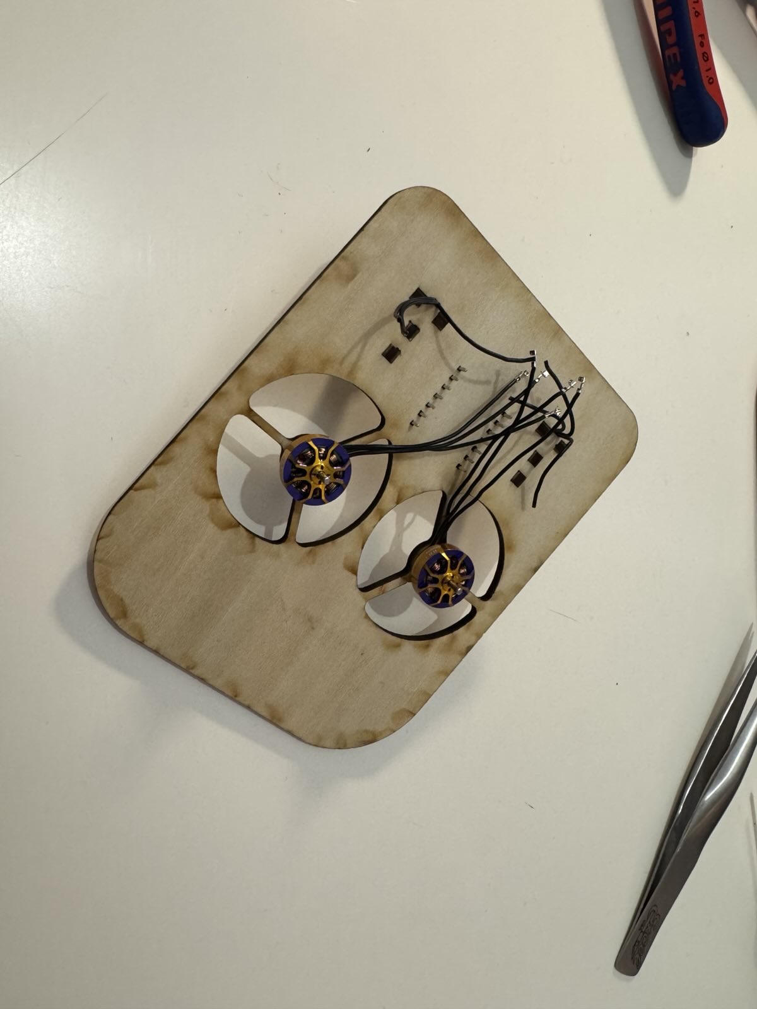
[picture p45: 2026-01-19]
1_Electronique/Assemblage/5.jpg

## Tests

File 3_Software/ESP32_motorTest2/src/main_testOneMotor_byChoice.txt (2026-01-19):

// Motor test code
// Starts the ESC, sets it to be bidirectionnal, then beeps, then makes it go one way then the other over and over at low speeds

#include <Arduino.h>
#include "DShotESC.h"

#define PEAKSPEED 200 // Maximum throttle value to be applied (throttle between -999 and 999)

const int LED_PIN = LED_BUILTIN; // choose a free pin

// To ramp the motor to +-PEAKSPEED
int16_t motorSpeed = 0;    // Variable to hold the current motor speed
int increaseDirection = 1; // Direction of speed increase (1 for increasing, -1 for decreasing)

// Create an Electronic Speed Controller (ESC) object
DShotESC esc0;

void setup()
{
  // Serial.begin(115200); // Initialize serial communication for debugging
  pinMode(LED_PIN, OUTPUT);

  // Test the 4 motors
  // esc0.install(GPIO_NUM_43, RMT_CHANNEL_0); // Connect ESC to GPIO pin 43 using RMT channel 0 (motor 1)
  // esc0.install(GPIO_NUM_8, RMT_CHANNEL_1); // Connect ESC to GPIO pin 8 using RMT channel 1 )(motor 2)
  // esc0.install(GPIO_NUM_7, RMT_CHANNEL_2); // Connect ESC to GPIO pin 7 using RMT channel 2 (motor 3)
  // esc0.install(GPIO_NUM_44, RMT_CHANNEL_3); // Connect ESC to GPIO pin 44 using RMT channel 3 (motor 4)

  esc0.init();             // Initialize the ESC
  esc0.setReversed(false); // Set normal rotation direction (not reversed)
  esc0.set3DMode(true);    // Enable bidirectional mode (allows forward and reverse)

  // Generate a sequence of beeps to indicate ESC is ready
  for (int i = 0; i < 5; i++)
  {
    esc0.beep(i); // Send 5 beep commands with increasing index
  }
}

void loop()
{
  // Ramp motor speed up and down between -PEAKSPEED and +PEAKSPEED
  esc0.sendThrottle3D(motorSpeed);     // Send the calculated throttle value to the ESC
  motorSpeed += increaseDirection * 5; // Increment or decrement motor speed

  // Reverse direction if peak speed is reached
  if (motorSpeed >= PEAKSPEED || motorSpeed <= -PEAKSPEED)
  {
    increaseDirection *= -1; // Reverse direction when reaching peak speed
  }

  // Small delay for stability (do not ramp too fast!)
  delay(20);

  // Toggle built-in LED depending on motor direction
  digitalWrite(LED_PIN, motorSpeed > 0 ? HIGH : LOW);
}

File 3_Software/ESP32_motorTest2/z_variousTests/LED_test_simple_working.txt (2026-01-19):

#include <Arduino.h>
#include <Adafruit_NeoPixel.h>

#define LED_PIN     18      // NeoPixel on IO18
#define LED_COUNT   1       // Single on-board pixel
#define BRIGHTNESS  20      // 0..255 (keep it low for eyes/power)

Adafruit_NeoPixel pixel(LED_COUNT, LED_PIN, NEO_GRB + NEO_KHZ800);

static inline void setColor(uint8_t r, uint8_t g, uint8_t b) {
  pixel.setPixelColor(0, pixel.Color(r, g, b));
  pixel.show();
}

void setup() {
  Serial.begin(115200);
  delay(1000);              // Give USB-serial a moment
  pixel.begin();
  pixel.setBrightness(BRIGHTNESS);
  setColor(0, 0, 0);        // start off
}

void loop() {
  setColor(255, 0, 0);  delay(500);   // Red
  setColor(0, 255, 0);  delay(500);   // Green
  setColor(0, 0, 255);  delay(500);   // Blue
  setColor(0, 0, 0);    delay(500);   // Off
}

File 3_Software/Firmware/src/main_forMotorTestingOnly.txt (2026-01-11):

#include <Arduino.h>

// Include file for all global variables
#include "hovercraft_variables.h"

// Include all subsystem headers
#include <motor_ctrl.h>
#include <motor_mixer.h>
// #include <imu.h>
// #include <wifi_manager.h>
// #include <network_piloting.h>
// #include <ir_sensors.h>
// #include <battery_monitor.h>
// #include <pid_controller.h>
// #include <camera_placeholder.h>

// RTOS includes
// #include <freertos/FreeRTOS.h>
// #include <freertos/task.h>

// Motor controller with global power scaler, defined in hovercraft_variables.h!!
MotorCtrl motorCtrl(global_AllMotorsScalePercent); // global power scaler reduces the max power to avoid smoking motors, adjust depending on kV of motors

// Mixer that uses the motor controller
MotorMixer motorMixer(motorCtrl); // Gives control mixer access to motor controller

// Debug ramp test (matches the standalone sketch behavior)
#define PEAKSPEED_PERCENT 20.0f // percent between -100.0f and 100.0f
static float motorSpeedPercent = 0.0f;
static int increaseDirection = 1;

void setup()
{
  // Serial is handy to confirm the firmware is running
  Serial.begin(115200);
  delay(500);

  // Init motors
  // Args: fl_pin, fr_pin, bl_pin, br_pin,
  //       reversedFL, reversedFR, reversedBL, reversedBR
  motorCtrl.init(
      global_PIN_MOTOR_FL,
      global_PIN_MOTOR_FR,
      global_PIN_MOTOR_BL,
      global_PIN_MOTOR_BR,
      global_MotorsReversedFL, // flag, if FL motor is reversed or not
      global_MotorsReversedFR, // flag, if FR motor is reversed or not
      global_MotorsReversedBL, // flag, if BL motor is reversed or not
      global_MotorsReversedBR  // flag, if BR motor is reversed or not
  );

  // Start at 0 throttle (arming-safe)
  delay(20);
  motorCtrl.setAllPercent(0.0f, 0.0f, 0.0f, 0.0f);

  delay(20);

  // Init mixer
  motorMixer.init();
  delay(100);
}

void loop()
{
  /*   // Test with percent control
    motorCtrl.setAllPercent(motorSpeedPercent, motorSpeedPercent, motorSpeedPercent, motorSpeedPercent);
    motorSpeedPercent += increaseDirection * 1.0f;
    if (motorSpeedPercent >= PEAKSPEED_PERCENT || motorSpeedPercent <= -PEAKSPEED_PERCENT)
    {
      increaseDirection *= -1;
    } */

  /*   // Use motor mixer to test, instead of motorCtrl directly, keep doing ramps tests, for now only in lift
    motorMixer.setLift(motorSpeedPercent);
    motorMixer.setThrust(motorSpeedPercent);
    motorMixer.setDiffThrust(0.0);
    motorSpeedPercent += increaseDirection * 1.0f;
    if (motorSpeedPercent >= PEAKSPEED_PERCENT || motorSpeedPercent <= 0.0f)
    {
      increaseDirection *= -1;
    } */

  motorMixer.setLift(40.0f);
  motorMixer.setThrust(60.0f);

  /*   // Use motor mixer to test, instead of motorCtrl directly, keep doing ramps tests, for now only in lift
    motorMixer.setLift(motorSpeedPercent);
    motorMixer.setThrust(motorSpeedPercent);
    motorMixer.setDiffThrust(0.0);
    if (motorSpeedPercent < PEAKSPEED_PERCENT / 2)
    {
      motorSpeedPercent += increaseDirection * 0.1f;
    }
    else
    {
      motorSpeedPercent = 100.0f;
    }

    if (motorSpeedPercent >= PEAKSPEED_PERCENT || motorSpeedPercent <= 0.0f)
    {
      increaseDirection *= -1;
    } */

  /*   if (motorSpeedPercent < 80.0f)
    {
      motorSpeedPercent += 1.0f;

      motorCtrl.setAllPercent(motorSpeedPercent, motorSpeedPercent, motorSpeedPercent, motorSpeedPercent);

      motorMixer.setLift(motorSpeedPercent);
      motorMixer.setThrust(motorSpeedPercent);
  }
  */

  /*   // motorMixer.setLiftThrustDiff(lift%, thrust%, diffThrust%)
    motorMixer.setLiftThrustDiff(40, 60, 0); */

  delay(30);
}

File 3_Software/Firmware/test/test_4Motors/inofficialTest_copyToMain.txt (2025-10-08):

#include <Arduino.h>

// Include all subsystem headers
#include <motor_ctrl.h>

// Added definitions for the test
const int LED_PIN = LED_BUILTIN;
const int16_t PEAKSPEED = 750; // select between 0 and +999, extreme values may not work with all ESCs

// Global subsystem instances
MotorCtrl motorCtrl;

void setup()
{
  // Initialize serial communication
  Serial.begin(115200);
  pinMode(LED_PIN, OUTPUT);
  // Initialize motorCtrl with front left on GPIO1; use dummy pins for others
  motorCtrl.init(GPIO_NUM_1, GPIO_NUM_2, GPIO_NUM_3, GPIO_NUM_4);
}

void loop()
{
  // Motor speed ramp test using motor_ctrl functions
  static int16_t motorSpeed = 0;
  static int increaseDirection = 1;

  motorCtrl.setFrontLeftPercent(motorSpeed);
  motorCtrl.setFrontRightPercent(motorSpeed);
  motorCtrl.setBackLeftPercent(motorSpeed);
  motorCtrl.setBackRightPercent(motorSpeed);
  motorCtrl.update();

  motorSpeed += increaseDirection * 5;
  // Reverse direction at peak speed
  if (motorSpeed >= PEAKSPEED || motorSpeed <= -PEAKSPEED)
  {
    increaseDirection *= -1;
  }

  digitalWrite(LED_PIN, motorSpeed > 0 ? HIGH : LOW);
  delay(20);
}

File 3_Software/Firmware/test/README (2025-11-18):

This directory is intended for PlatformIO Test Runner and project tests.

Unit Testing is a software testing method by which individual units of
source code, sets of one or more MCU program modules together with associated
control data, usage procedures, and operating procedures, are tested to
determine whether they are fit for use. Unit testing finds problems early
in the development cycle.

More information about PlatformIO Unit Testing:
- https://docs.platformio.org/en/latest/advanced/unit-testing/index.html

---

## Quick Start Guide

### Folder Structure

```
test/
├── test_blink/
│   └── test_main.cpp
├── test_4Motors/
│   └── test_4Motors.cpp
└── README
```

**Rule:** Each test goes in `test/test_<feature_name>/test_<feature_name>.cpp`

### Required Test File Structure

```cpp
#include <Arduino.h>
#include <unity.h>

void setUp(void) { }        // Before each test
void tearDown(void) { }     // After each test

void test_something(void) {
  TEST_ASSERT_EQUAL(expected, actual);
}

void setup() {
  delay(2000);
  UNITY_BEGIN();
  RUN_TEST(test_something);
}

void loop() {
  UNITY_END();
}
```

### Common Assertions

```cpp
TEST_ASSERT_EQUAL(expected, actual);
TEST_ASSERT_TRUE(condition);
TEST_ASSERT_FALSE(condition);
TEST_ASSERT_GREATER_THAN(threshold, value);
TEST_ASSERT_NULL(pointer);
TEST_ASSERT_EQUAL_STRING(expected, actual);
```

### Configuration (platformio.ini)

```ini
test_framework = unity
test_build_src = no    # Required to avoid conflicts with src/main.cpp
```

### Running Tests

```bash
pio test           # Run all tests
pio test -vv       # Verbose output

Or to be more explicit:

pio test -f test_blink -e seeed_xiao_esp32s3

Where:

-f test_blink filters to only the test_blink folder
-e seeed_xiao_esp32s3 specifies the environment (optional)

C:\Users\leonv\.platformio\penv\Scripts\platformio.exe test
```

### Function Naming

- `setUp()` / `tearDown()` - lowercase, runs before/after each test
- `test_<name>()` - starts with `test_`, lowercase with underscores
- `setup()` / `loop()` - Arduino entry points (required)

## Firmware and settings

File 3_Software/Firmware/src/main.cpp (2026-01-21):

#include <Arduino.h>

#include <math.h>

// RTOS includes
#include <freertos/FreeRTOS.h>
#include <freertos/task.h>
#include <freertos/queue.h>

// Reset reason / diagnostics
#include "esp_system.h"
#include "esp_heap_caps.h"

// Include file for all global variables
#include "hovercraft_variables.h"

// Include all subsystem headers
#include <motor_ctrl.h>
#include <motor_mixer.h>
#include <imu.h>
#include <wifi_manager.h>
#include <network_piloting.h>
#include <ir_sensors.h>
#include <battery_monitor.h>
#include <pid_controller.h>
#include <heading_controller.h>
#include <camera_placeholder.h>
#include <autonomous_sequence.h>

// **************************************************
// DEFINE ALL OBJECTS THAT ARE NEEDED
// **************************************************
// Motor controller with global power scaler, defined in hovercraft_variables.h!!
MotorCtrl motorCtrl(global_AllMotorsScalePercent); // global power scaler reduces the max power to avoid smoking motors, adjust depending on kV of motors

// Mixer that uses the motor controller
MotorMixer motorMixer(motorCtrl); // Gives control mixer access to motor controller

// Network + WiFi helpers
WifiManager wifiManager;
NetworkPiloting networkPiloting;

// IMU (Fermion 10DOF: ADXL345 + ITG3205 + QMC/VCM5883L + BMP280)
IMU imu(global_ComplementaryFilter_yawAlpha);

// IR Line Sensors
IRSensors irSensors((int)global_PIN_IR_SENSOR_BM,
                    (int)global_PIN_IR_SENSOR_FL,
                    (int)global_PIN_IR_SENSOR_FR,
                    global_IRSensorDistance_a_meters,
                    global_IRSensorDistance_b_meters); // pins and distance a: sides,b: base between sensors for an isosceles triangle

// Battery monitor (Betaflight-style voltage/current sensing via ADC + divider ratios)
BatteryMonitor batteryMonitor;

// Autonomous "M" mode sequencer (time-based heading/thrust script)
AutonomousSequence autonomousSequence;

// Low-battery safety flags (set by battery task, read by other tasks).
static volatile bool g_lowBatteryLedSolidOn = false;
static volatile bool g_lowBatteryMotorCutoff = false;

// Struct+Queue for communication between WIFI-Control and Motor Management
struct ControlSetpoints
{
  float lift;
  float thrust;
  float diffThrust;
  bool motorsEnabled;
  bool liftEnabled;
};
QueueHandle_t g_controlQueue = nullptr;
static ControlSetpoints g_latestSetpoints{0.0f, 0.0f, 0.0f, false, false};
static portMUX_TYPE g_setpointsMux = portMUX_INITIALIZER_UNLOCKED;

// Shared IMU data for controllers (updated by IMU task, consumed by motor/control task)
static volatile float g_yawRateMeasured_dps = 0.0f;  // yaw rate (deg/s), sign consistent with IMU yaw integration
static volatile uint32_t g_lastYawRateUpdate_us = 0; // micros() timestamp

// Shared yaw heading estimate from the complementary filter (deg, typically 0..360).
static volatile float g_yawMeasured_deg = 0.0f;
static volatile uint32_t g_lastYawUpdate_us = 0; // micros() timestamp

// Shared IR line crossing event (produced by task_calcIrSensors, consumed by motor/control task).
static portMUX_TYPE g_irMux = portMUX_INITIALIZER_UNLOCKED;
static volatile bool g_irLineEventFresh = false;
static float g_irAlpha_deg = NAN;
static float g_irVPerp_mps = NAN;
static float g_irHeadingAtLine_deg = NAN;
static uint32_t g_irLineEventMs = 0;

// Battery telemetry is produced by the battery task and sent by the wifi task.
static portMUX_TYPE g_telemetryMux = portMUX_INITIALIZER_UNLOCKED;
static float g_battVoltage_V = 0.0f;
static float g_battCurrent_A = 0.0f;
static float g_battUsed_mAh = 0.0f;
static bool g_battTelemetryPending = false;

// RTC retained diagnostics (helps when the board keeps rebooting).
RTC_DATA_ATTR static uint32_t g_bootCount = 0;

// Runtime-tunable PID gains (editable via /pid without reflashing).
// These are initialized from the compile-time defaults in hovercraft_variables.
struct RuntimePidTunings
{
  float yawKp;
  float yawKi;
  float yawKd;
  float headingKp;
  float headingKi;
  float headingKd;
};

static portMUX_TYPE g_pidMux = portMUX_INITIALIZER_UNLOCKED;
static RuntimePidTunings g_pidTunings{
    global_YawRatePid_Kp,
    global_YawRatePid_Ki,
    global_YawRatePid_Kd,
    global_HeadingPid_Kp,
    global_HeadingPid_Ki,
    global_HeadingPid_Kd};
static bool g_pidTuningsDirty = false;

// New mode: heading hold (triggered via web UI "M" button).
static volatile bool g_headingHoldActive = false;
static volatile float g_headingTarget_deg = 0.0f;

static inline float wrap360_local(float deg)
{
  if (!isfinite(deg))
    return 0.0f;
  while (deg >= 360.0f)
    deg -= 360.0f;
  while (deg < 0.0f)
    deg += 360.0f;
  return deg;
}

static void setHeading(float heading_deg)
{
  g_headingTarget_deg = wrap360_local(heading_deg);
  g_headingHoldActive = true;
}

static void cancelHeadingHold()
{
  g_headingHoldActive = false;
}

static inline void queueLatestSetpointsSnapshot()
{
  if (g_controlQueue == nullptr)
  {
    return;
  }
  ControlSetpoints snap;
  portENTER_CRITICAL(&g_setpointsMux);
  snap = g_latestSetpoints;
  portEXIT_CRITICAL(&g_setpointsMux);
  xQueueOverwrite(g_controlQueue, &snap);
}

static inline const char *resetReasonToString(esp_reset_reason_t r)
{
  switch (r)
  {
  case ESP_RST_UNKNOWN:
    return "UNKNOWN";
  case ESP_RST_POWERON:
    return "POWERON";
  case ESP_RST_EXT:
    return "EXT";
  case ESP_RST_SW:
    return "SW";
  case ESP_RST_PANIC:
    return "PANIC";
  case ESP_RST_INT_WDT:
    return "INT_WDT";
  case ESP_RST_TASK_WDT:
    return "TASK_WDT";
  case ESP_RST_WDT:
    return "WDT";
  case ESP_RST_DEEPSLEEP:
    return "DEEPSLEEP";
  case ESP_RST_BROWNOUT:
    return "BROWNOUT";
  case ESP_RST_SDIO:
    return "SDIO";
  default:
    return "(other)";
  }
}

extern "C" void vApplicationStackOverflowHook(TaskHandle_t xTask, char *pcTaskName)
{
  (void)xTask;
  // Note: stack overflows often corrupt state; keep this minimal.
  Serial.printf("[FREERTOS] Stack overflow in task: %s\n", pcTaskName ? pcTaskName : "(null)");
  Serial.flush();
  esp_restart();
}

extern "C" void vApplicationMallocFailedHook(void)
{
  Serial.println("[FREERTOS] Malloc failed");
  Serial.printf("[HEAP] free=%u min=%u\n", (unsigned)esp_get_free_heap_size(), (unsigned)heap_caps_get_minimum_free_size(MALLOC_CAP_8BIT));
  Serial.flush();
  esp_restart();
}

// **************************************************
// DEFINE/DECLARE ALL TASK HANDLES
// **************************************************
// Declare task handles
TaskHandle_t taskH_Blink = NULL; // just for quick testing, delete later

TaskHandle_t taskH_wifi = NULL;            // task: hosting the webserver/website to get user controls
TaskHandle_t taskH_imu = NULL;             // task: reading IMU and applying filtering
TaskHandle_t taskH_motorManagement = NULL; // task: gets Setpoint, calls Mixer, sends DShot-commands to MotorCtrl
TaskHandle_t taskH_irSensors = NULL;       // task: reading IR-Sensors
TaskHandle_t taskH_calcIrSensors = NULL;   // task: calculating angle+perpendicular velocity from IR-Sensor readings
TaskHandle_t taskH_batteryMonitor = NULL;  // task: reading battery voltage/current, warning on low battery and capacity calculation

// **************************************************
// TASK FUNCTIONS THAT ARE CALLED BY SCHEDULER
// **************************************************
void task_blink(void *parameter)
{
  for (;;)
  { // Infinite loop
    if (g_lowBatteryLedSolidOn)
    {
      // Low battery indicator: keep LED solid ON.
      digitalWrite(LED_PIN, HIGH);
      vTaskDelay(200 / portTICK_PERIOD_MS);
      continue;
    }

    digitalWrite(LED_PIN, HIGH);
    // Serial.println("task_blink: LED ON");
    vTaskDelay(1000 / portTICK_PERIOD_MS); // 1000ms
    digitalWrite(LED_PIN, LOW);
    // Serial.println("task_blink: LED OFF");
    vTaskDelay(1000 / portTICK_PERIOD_MS);
    // Serial.print("task_blink running on core ");
    // Serial.println(xPortGetCoreID());
  }
}

void task_wifiManager(void *parameter)
{
  static uint32_t lastDiagMs = 0;

  for (;;)
  {
    const uint32_t nowMs = millis();

    // Periodic diagnostics (helps identify stack/heap pressure leading to WDT/panic).
    if ((nowMs - lastDiagMs) >= 5000)
    {
      lastDiagMs = nowMs;
      const uint32_t freeHeap = (uint32_t)esp_get_free_heap_size();
      const uint32_t minHeap = (uint32_t)heap_caps_get_minimum_free_size(MALLOC_CAP_8BIT);
      const uint32_t stMotor = (uint32_t)uxTaskGetStackHighWaterMark(taskH_motorManagement) * (uint32_t)sizeof(StackType_t);
      const uint32_t stImu = (uint32_t)uxTaskGetStackHighWaterMark(taskH_imu) * (uint32_t)sizeof(StackType_t);
      const uint32_t stWifi = (uint32_t)uxTaskGetStackHighWaterMark(taskH_wifi) * (uint32_t)sizeof(StackType_t);
      const uint32_t stBat = (uint32_t)uxTaskGetStackHighWaterMark(taskH_batteryMonitor) * (uint32_t)sizeof(StackType_t);
      // Serial.printf("[DIAG] heap_free=%lu heap_min=%lu stackB motor=%lu imu=%lu wifi=%lu bat=%lu\n",
      //               (unsigned long)freeHeap,
      //               (unsigned long)minHeap,
      //               (unsigned long)stMotor,
      //               (unsigned long)stImu,
      //               (unsigned long)stWifi,
      //               (unsigned long)stBat);
    }

    vTaskDelay(50 / portTICK_PERIOD_MS);
  }
}

void task_imu(void *parameter)
{
  (void)parameter;

  // Let other subsystems bring Serial up.
  vTaskDelay(200 / portTICK_PERIOD_MS);

  Serial.printf("[IMU] task running on core %d\n", xPortGetCoreID());
  imu.init();

  Serial.printf("[IMU] ready=%d accel=%d gyro=%d mag=%d baro=%d\n",
                (int)imu.isReady(), (int)imu.hasAccel(), (int)imu.hasGyro(), (int)imu.hasMag(), (int)imu.hasBaro());

  // Yaw complementary filter: mostly gyro, slow magnetometer correction
  imu.setYawFilterAlpha(global_ComplementaryFilter_yawAlpha);
  imu.resetYawToMag();

  // Optional: calibrate accel reference (keep craft still + level for ~1s)
  if (imu.hasAccel())
  {
    vTaskDelay(2000 / portTICK_PERIOD_MS); // wait 2 s before starting calibration
    Serial.println("[IMU] calibrating accel reference...");
    imu.calibrateAccelReference(200, 5);
    Serial.println("[IMU] accel calibration done");
  }

  // Run gyro integration fast for stable rate control.
  TickType_t lastWake = xTaskGetTickCount();
  TickType_t period = pdMS_TO_TICKS(5); // 200 Hz
  if (period == 0)
    period = 1;

  uint32_t lastMagMs = 0;
  uint32_t lastPrintMs = 0;

  for (;;)
  {
    float gx = NAN, gy = NAN, gz = NAN;
    imu.getGyro_raw(&gx, &gy, &gz);

    // Convert to yaw rate in deg/s.
    // Note: We keep the existing yaw-rate sign convention used by the inner yaw-rate controller.
    // (It may differ from the yaw angle integration sign; the controller/mixer convention wins here.)
    const float yawRate_dps = gz * (180.0f / PI);
    if (isfinite(yawRate_dps))
    {
      g_yawRateMeasured_dps = yawRate_dps;
      g_lastYawRateUpdate_us = micros();
    }

    // Read magnetometer at a slower rate to reduce I2C load; integrate gyro every loop.
    float heading_deg = NAN;
    if (imu.hasMag() && (millis() - lastMagMs) >= 50)
    {
      int16_t mx, my, mz;
      float head;
      imu.getMag_raw(&mx, &my, &mz, &head);
      heading_deg = head;
      lastMagMs = millis();

      // For debugging:
      // print magnetometer-based heading, gyro-Integrated heading and complementary filter results#
      // Serial.printf("[IMU] Mag Heading=%.1f deg, Gyro Integrated Yaw=%.1f deg, Comp Filter Yaw=%.1f deg\n",
      //               heading_deg,
      //               imu.getYawGyro_deg(),
      //               imu.getYaw_deg());

      // Mag, Gyro, Comp
      // Serial.printf("%0.2f,%0.2f,%0.2f\n", heading_deg, imu.getYawGyro_deg(), imu.getYaw_deg());
    }

    imu.updateYawComplementaryFrom(gz, heading_deg);

    // Share heading estimate for controllers.
    const float yaw_deg = imu.getYaw_deg();
    if (isfinite(yaw_deg))
    {
      g_yawMeasured_deg = yaw_deg;
      g_lastYawUpdate_us = micros();
    }

    if ((millis() - lastPrintMs) >= 200)
    {
      lastPrintMs = millis();
      // Serial.printf("[IMU] yawRate=%.1f dps yaw=%.1f deg\n", yawRate_dps, imu.getYaw_deg());
    }

    vTaskDelayUntil(&lastWake, period);
  }
}

void task_motorManagement(void *parameter)
{
  MotorMixer *mixer = static_cast<MotorMixer *>(parameter);

  auto yawRateSetpointFromSteeringPercent_dps = [](float steeringPercent) -> float
  {
    // Betaflight-style "Actual Rates" inspired mapping.
    // Input: steeringPercent in [-100..100]. Output: yaw-rate setpoint in deg/s.
    const float stick = constrain(steeringPercent, -100.0f, 100.0f) * 0.01f; // -1..1
    const float a = fabsf(stick);

    const float maxRate_dps = fmaxf(0.0f, global_MaxYawRateSetpoint_dps);
    float center_dps = fmaxf(0.0f, global_YawCenterSensitivity);
    if (center_dps > maxRate_dps)
      center_dps = maxRate_dps;

    const float expo = constrain(global_YawRateExpo, 0.0f, 1.0f);
    const float p = 3.0f + 2.0f * expo; // expo=0 -> cubic, expo=1 -> quintic

    const float rateAbs_dps = center_dps * a + (maxRate_dps - center_dps) * powf(a, p);
    return (stick < 0.0f) ? -rateAbs_dps : rateAbs_dps;
  };

  PIDController yawRatePid;
  HeadingController headingPid;

  auto applyPidTunings = [&](const RuntimePidTunings &t)
  {
    yawRatePid.init(
        t.yawKp,
        t.yawKi,
        t.yawKd,
        global_YawRatePid_OutputLimit,
        global_YawRatePid_IntegratorLimit);

    headingPid.init(
        t.headingKp,
        t.headingKi,
        t.headingKd,
        global_HeadingPid_OutputLimit_dps,
        global_HeadingPid_IntegratorLimit_dps);
  };

  RuntimePidTunings localTunings;
  portENTER_CRITICAL(&g_pidMux);
  localTunings = g_pidTunings;
  portEXIT_CRITICAL(&g_pidMux);
  applyPidTunings(localTunings);

  bool lastHeadingHoldActive = false;
  bool lastMotorsEnabled = false;
  bool lastLiftEnabledWhileArmed = false;

  ControlSetpoints mySetPoint{0, 0, 0, false, false};

  // Control loop timing
  // Use microsecond scheduling to support fractional millisecond periods
  // (e.g. 400 Hz -> 2500 us). vTaskDelayUntil() works in ticks and would
  // truncate to whole milliseconds.
  const float controlRateHz = fmaxf(1.0f, global_ControlLoopRate_Hz);
  const uint32_t controlPeriodUs = (uint32_t)lroundf(1e6f / controlRateHz);
  uint32_t nextWakeUs = micros();
  uint32_t lastUpdateUs = nextWakeUs;

  for (;;)
  {
    // Apply PID tuning updates (from /pid) at a safe point.
    bool pidDirty = false;
    portENTER_CRITICAL(&g_pidMux);
    pidDirty = g_pidTuningsDirty;
    if (pidDirty)
    {
      localTunings = g_pidTunings;
      g_pidTuningsDirty = false;
    }
    portEXIT_CRITICAL(&g_pidMux);
    if (pidDirty)
    {
      applyPidTunings(localTunings);
      Serial.printf("[PID] updated yaw(kp=%.4f ki=%.4f kd=%.4f) heading(kp=%.4f ki=%.4f kd=%.4f)\n",
                    (double)localTunings.yawKp,
                    (double)localTunings.yawKi,
                    (double)localTunings.yawKd,
                    (double)localTunings.headingKp,
                    (double)localTunings.headingKi,
                    (double)localTunings.headingKd);
    }

    const uint32_t nowUs = micros();
    float dt_s = (nowUs - lastUpdateUs) * 1e-6f;
    lastUpdateUs = nowUs;
    if (!isfinite(dt_s) || dt_s < 0.001f)
      dt_s = 0.001f;
    if (dt_s > 0.05f)
      dt_s = 0.05f;

    if (g_controlQueue != nullptr)
    {
      // Non blocking receive, timeout 0 ticks
      if (xQueueReceive(g_controlQueue, &mySetPoint, 0) == pdPASS)
      {
        // Got new setpoints
      }
    }

    // Work on a copy so autonomous overrides don't permanently mutate the last user setpoints.
    ControlSetpoints appliedSetpoints = mySetPoint;

    // Battery safety gate: if cutoff is active, force motors OFF regardless of user arming.
    const bool effectiveMotorsEnabled = appliedSetpoints.motorsEnabled && !g_lowBatteryMotorCutoff;

    // Update autonomous sequence (M-Mode). This may override thrust and heading.
    const uint32_t lastYawUs = g_lastYawUpdate_us;
    const bool yawFresh = (lastYawUs != 0) && ((nowUs - lastYawUs) < 150000); // 150ms freshness
    const float yawMeasured_deg = yawFresh ? g_yawMeasured_deg : 0.0f;

    // Consume a one-shot IR line event (if available) for the autonomous sequence.
    bool lineEventFresh = false;
    float lineAlpha_deg = NAN;
    float lineVPerp_mps = NAN;
    float headingAtLine_deg = NAN;
    portENTER_CRITICAL(&g_irMux);
    lineEventFresh = g_irLineEventFresh;
    if (lineEventFresh)
    {
      lineAlpha_deg = g_irAlpha_deg;
      lineVPerp_mps = g_irVPerp_mps;
      headingAtLine_deg = g_irHeadingAtLine_deg;
      g_irLineEventFresh = false;
    }
    portEXIT_CRITICAL(&g_irMux);

    autonomousSequence.update(millis(),
                              yawMeasured_deg,
                              yawFresh,
                              effectiveMotorsEnabled,
                              lineEventFresh,
                              lineAlpha_deg,
                              lineVPerp_mps,
                              headingAtLine_deg);

    if (autonomousSequence.isActive())
    {
      // During M-Mode we override user commands.
      // - Calibration must keep all motors at 0 output for stability.
      // - After calibration, thrust is overridden by the sequence.
      const AutonomousSequence::State s = autonomousSequence.state();
      const bool holdMotorsAtZero = (s == AutonomousSequence::State::Calibrating) || (s == AutonomousSequence::State::WaitingForArm);

      if (holdMotorsAtZero)
      {
        appliedSetpoints.thrust = 0.0f;
        appliedSetpoints.diffThrust = 0.0f;
        appliedSetpoints.lift = 0.0f;
        appliedSetpoints.liftEnabled = false;
      }
      else
      {
        if (autonomousSequence.overrideThrust())
        {
          appliedSetpoints.thrust = constrain(autonomousSequence.thrustOverride_percent(), -100.0f, 100.0f);
        }
        appliedSetpoints.diffThrust = 0.0f;
      }

      if (autonomousSequence.wantsHeadingHold())
      {
        setHeading(autonomousSequence.headingTarget_deg());
      }
    }

    // Apply whatever values are in mySetPoint (last known setpoints)
    // Enforce emergency override at MotorCtrl level as well (edge-triggered to avoid spamming DShot).
    if (effectiveMotorsEnabled != lastMotorsEnabled)
    {
      motorCtrl.setMotorsEnabled(effectiveMotorsEnabled);
      lastMotorsEnabled = effectiveMotorsEnabled;

      // When disarming, also clear lift-edge tracking.
      if (!effectiveMotorsEnabled)
      {
        lastLiftEnabledWhileArmed = false;
      }
    }

    // Compute yaw rate setpoint from steering input.
    // `diffThrust` coming from the app is interpreted as yaw-rate command in percent [-100..100].
    float yawRateSetpoint_dps = yawRateSetpointFromSteeringPercent_dps(appliedSetpoints.diffThrust);

    const uint32_t lastGyroUs = g_lastYawRateUpdate_us;
    const bool gyroFresh = (lastGyroUs != 0) && ((nowUs - lastGyroUs) < 50000); // 50ms freshness
    const float yawRateMeasured_dps = gyroFresh ? g_yawRateMeasured_dps : 0.0f;

    const bool headingHold = g_headingHoldActive;
    if (headingHold && !lastHeadingHoldActive)
    {
      headingPid.reset();
    }
    lastHeadingHoldActive = headingHold;

    // yawFresh/yawMeasured_deg computed above (also used by autonomous sequencer)

    if (headingHold)
    {
      // Outer loop: heading error -> yaw-rate setpoint (deg/s).
      // Keep the inner loop unchanged.
      if (yawFresh && gyroFresh)
      {
        yawRateSetpoint_dps = headingPid.update(g_headingTarget_deg, yawMeasured_deg, yawRateMeasured_dps, dt_s);
      }
      else
      {
        headingPid.reset();
        yawRateSetpoint_dps = 0.0f;
      }
    }

    // If the sequence finishes or is aborted, force-stop motors and exit M-Mode.
    if (autonomousSequence.consumeExitRequest())
    {
      cancelHeadingHold();

      portENTER_CRITICAL(&g_setpointsMux);
      g_latestSetpoints.motorsEnabled = false;
      g_latestSetpoints.liftEnabled = false;
      g_latestSetpoints.lift = 0.0f;
      g_latestSetpoints.thrust = 0.0f;
      g_latestSetpoints.diffThrust = 0.0f;
      portEXIT_CRITICAL(&g_setpointsMux);

      queueLatestSetpointsSnapshot();

      motorCtrl.setMotorsEnabled(false);
      mixer->setLiftThrustDiff(0.0f, 0.0f, 0.0f);

      Serial.println("[AUTO] sequence exit -> motors OFF, M-Mode OFF");
    }

    float diffCmd = 0.0f;
    if (effectiveMotorsEnabled && gyroFresh)
    {
      diffCmd = yawRatePid.update(yawRateSetpoint_dps, yawRateMeasured_dps, dt_s);
      diffCmd = constrain(diffCmd, -100.0f, 100.0f);
    }
    else
    {
      yawRatePid.reset();
      diffCmd = 0.0f;
    }

    // Apply mixer outputs once per loop to reduce DShot/RMT load.
    float liftCmd = 0.0f;
    float thrustCmd = 0.0f;
    float diffCmdToMixer = 0.0f;

    if (!effectiveMotorsEnabled)
    {
      // Keep the selected lift setpoint latched even while disarmed,
      // so arming immediately applies the preselected lift percentage.
      liftCmd = appliedSetpoints.liftEnabled ? appliedSetpoints.lift : 0.0f;
      thrustCmd = 0.0f;
      diffCmdToMixer = 0.0f;
    }
    else
    {
      // Lift OFF only affects the two front motors.
      const bool liftEnabled = appliedSetpoints.liftEnabled;
      if (!liftEnabled && lastLiftEnabledWhileArmed)
      {
        // Falling edge: hard-stop lift motors immediately.
        motorCtrl.applyLiftOff();
      }
      lastLiftEnabledWhileArmed = liftEnabled;

      liftCmd = liftEnabled ? appliedSetpoints.lift : 0.0f;
      thrustCmd = appliedSetpoints.thrust;
      diffCmdToMixer = diffCmd;
    }

    mixer->setLiftThrustDiff(liftCmd, thrustCmd, diffCmdToMixer);
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
void loop()
{
  // Nothing to do here
}

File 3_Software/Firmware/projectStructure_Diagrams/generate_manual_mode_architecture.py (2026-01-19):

"""Generate the growing 'manual mode' architecture overview.

This diagram is intentionally a conceptual, high-level view. It will grow step by
step as manual mode gains features.

Current nodes (requested):
- WiFi (SoftAP + Web UI / WebSocket commands)
- Main (application entry point + RTOS tasks + control queue)
- IMU
- Filter (yaw complementary filter)
- hovercraft_variables (global config)
- Motors (mixer + controller + ESC/motors)

This script generates:
- a high-level overview diagram
- sub-diagrams when a block becomes too detailed (clearly labeled)

Requires:
- `pip install diagrams`
- Graphviz `dot` on PATH
"""

from __future__ import annotations

import os
import sys
from pathlib import Path


def _print_prereq_help() -> None:
    print(
        "Missing Graphviz executable 'dot'.\n\n"
        "Install Graphviz and ensure it is on PATH:\n"
        "  - Windows (winget): winget install Graphviz.Graphviz\n"
        "  - Windows (choco):  choco install graphviz\n\n"
        "After installing, reopen the terminal and run this script again.\n"
    )


def _check_graphviz_dot_on_path() -> bool:
    from shutil import which

    return which("dot") is not None


def _diagram_style() -> tuple[dict[str, str], dict[str, str], dict[str, str]]:
    graph_attr = {"labelloc": "t", "fontsize": "20", "fontname": "Segoe UI", "rankdir": "LR", "splines": "spline", "pad": "0.2"}

    node_attr = {
        "fontname": "Segoe UI",
        "fontsize": "12",
        # Reduce icon/text collisions for image-based nodes (diagrams uses Graphviz images).
        "imagescale": "true",
        "imagepos": "mc",
        "labelloc": "b",
        # Add a bit of internal padding so the first label line doesn't touch the icon.
        "margin": "1.0,1.0",
    }
    edge_attr = {"fontname": "Segoe UI", "fontsize": "11"}
    return graph_attr, node_attr, edge_attr


def _icons_dir() -> Path:
    return Path(__file__).resolve().parent / "icons"


def _custom_icon(label: str, filename: str):
    from diagrams.custom import Custom

    return Custom(label, str(_icons_dir() / filename))


def _fallback_icon(label: str):
    # Used when none of the custom firmware icons fit.
    return _custom_icon(label, "cpp.png")


def _cfg(label: str):
    return _custom_icon(label, "Hovercraft_variables.png")


def _task(label: str):
    return _custom_icon(label, "task.png")


def _data(label: str):
    return _custom_icon(label, "data.png")


def _fn(label: str):
    return _custom_icon(label, "function.jpg")


def _motor(label: str):
    return _custom_icon(label, "motor.png")


def _generate_overview(output_dir: Path) -> Path:
    from diagrams import Cluster, Diagram, Edge

    out_path = output_dir / "manual_mode_architecture"
    graph_attr, node_attr, edge_attr = _diagram_style()

    with Diagram(
        "Firmware: Manual mode overview",
        filename=str(out_path),
        outformat="png",
        show=False,
        graph_attr=graph_attr,
        node_attr=node_attr,
        edge_attr=edge_attr,
    ):
        with Cluster("Configuration"):
            cfg = _cfg("hovercraft_variables\n(src/hovercraft_variables.*)")

        with Cluster("WiFi + Web control"):
            wifi = _fallback_icon("WifiManager\n(SoftAP)")
            web = _fallback_icon("NetworkPiloting\n(Web UI + WebSocket)")
            wifi >> Edge(label="SoftAP") >> web

        with Cluster("RTOS + App glue (src/main.cpp)"):
            main = _fn("Main\nsetup() + globals")
            queue = _data("g_controlQueue\n(len=1, overwrite)")
            task_wifi = _task("task_wifiManager\n(core0, ~50ms)\nnetworkPiloting.loop()")
            task_imu = _task("task_imu\n(core1, 200Hz)")
            task_motor = _task("task_motorManagement\n(core1, control loop)")
            task_batt = _task("task_batteryMonitor\n(core1, ~1Hz)\ntelemetry + cutoff")

            main >> Edge(label="creates") >> queue
            main >> Edge(label="starts") >> task_wifi
            main >> Edge(label="starts") >> task_imu
            main >> Edge(label="starts") >> task_motor
            main >> Edge(label="starts") >> task_batt

        with Cluster("Sensing"):
            imu = _fallback_icon("IMU\n(lib/imu)")
            filt = _fn("Yaw complementary filter\n(inside IMU)")
            imu >> Edge(label="gyro Z + mag heading") >> filt

        with Cluster("Actuation"):
            mixer = _fallback_icon("MotorMixer\n(lib/motor_mixer)")
            ctrl = _fallback_icon("MotorCtrl\n(lib/motor_ctrl)")
            motors = _motor("ESC + Motors\n(DSHOT)")
            mixer >> Edge(label="per-motor %") >> ctrl
            ctrl >> Edge(label="DSHOT") >> motors

        # Config wiring (from docs)
        cfg >> Edge(label="pins + tuning") >> main
        cfg >> Edge(label="SSID/PW + port + UI presets") >> web
        cfg >> Edge(label="yawAlpha") >> filt
        cfg >> Edge(label="motor pins + scaling") >> ctrl

        # Manual mode command flow
        web >> Edge(label="callbacks\n(lift/thrust/steering/arm)") >> queue
        task_motor << Edge(label="xQueueReceive(latest)") << queue
        task_wifi >> Edge(label="housekeeping") >> web
        task_batt >> Edge(label="sendTelemetry(V/A/mAh)") >> web

        # Control loop dependencies
        task_imu >> Edge(label="updates yaw/yawRate") >> filt
        filt >> Edge(label="shared yaw/yawRate") >> task_motor
        task_motor >> Edge(label="lift/thrust/diff") >> mixer

        # Sub-diagrams callouts (keep the overview readable)
        main >> Edge(label="subgraph:\nweb control details", style="dashed") >> web
        main >> Edge(label="subgraph:\ncontrol + actuation details", style="dashed") >> task_motor
        main >> Edge(label="subgraph:\nmotor task details", style="dashed") >> task_motor
        main >> Edge(label="subgraph:\nIMU + filter details", style="dashed") >> task_imu
        main >> Edge(label="subgraph:\nbattery safety + telemetry", style="dashed") >> task_batt

    return out_path.with_suffix(".png")
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

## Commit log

2025-10-07 +File and Function prototypes
2025-10-07 +Dshot +LED libary, added most basic motoTest for DShot
2025-10-08 +unit Test for LED_BUILTIN
2025-10-08 implemented 4 motor-ctrl in motor_ctrl.cpp - tested on motor0
2025-10-08 moved all src to libary. motor test in main.cpp functional, UnitTest not yet
2025-10-17 +worked on CAD
    [6_Inch_Prop_6035_V2_4_Blade.stl]
2025-10-22 raw prep for imu coding
2025-10-22 very basic read out of mpu, no corrections yet
    [main.cpp]
2025-10-22 corrected for constant sideways acceleration
    [main.cpp]
2025-10-23 CAD final
    [7-Pin Header - Male - 2.54mm.step, BetaFPV Meteor65 Pro Frame v2.step, MPU6050 Accelerometer.step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]
2025-10-23 rcmags MPU savepoint, problem is that position runs away
    [main.cpp]
2025-10-23 scrabbed all old code, started new but now with good calibration routing, no integration or else yet
2025-11-18 Added laser cut template
    [b01_top_plate_laser.dxf, b01_top_plate_laser_gut.dxf, b02_foam_duct_laser.dxf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]
2025-11-18 mignor updates to motor_crtl, significant updates to motor_mixer, IMU FOR NOW NOT FUNCTIONAL
2025-12-24 included math for IR-sensors, still open/ToDo: measure "a" (distance between sensors), find out how ISR works for analog values (placeholders in place)
2026-01-10 Added Website with Thrust throttle
2026-01-10 Changed IMU from MPU6050 to Fermion: 10 DOF IMU Sensor - ADXL345+ITG3205+VCM5883L+BMP280, implemented basic readings in fitting libaries, deleted old unused stuff
2026-01-10 + Slider Steering
2026-01-10 complementary filter v1 working
2026-01-11 battery monitor implemented, must be tested in reality!!!
2026-01-11 increased task_batteryMonitor stack size to stop the task from crashing
    [main.cpp]
2026-01-11 debug safepoint motors turn with debug-bypass
2026-01-11 Battery Monitor Task: fixed divider logic for correct measurements
    [hovercraft_variables.cpp]
2026-01-11 Unfixed, but understood: I finally found out, why it buggs sometimes, but not always. When commanding from a stillstand (0) to any speed that is to high, the motors dont follow. I need to send them a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
    [hovercraft_variables.cpp, main.cpp]
2026-01-11 motors should be working for further use, if not find help in main_forMotorTestingOnly.txt
2026-01-16 corrected yaw-rotaion from relative to absolute, changed a few variabels to hovercraft_variables
    [hovercraft_variables.cpp, main.cpp]
2026-01-16 PID Implemented for Yaw-stability, max rate can be set in hov_var
    Web controller UI significantly improved: larger touch areas, “drag-anywhere” interaction (not just the slider thumb), scroll/zoom disabled on smartphones (viewport/CSS/JS), and reliable snapping back to 0 using pointerId tracking plus reset on cancel/blur/visibilitychange.
    Motor control extended: new parameter global_NegativeRpmScaleFactor (default 2.0f), which amplifies all negative motor commands (reverse) to combat insimetry thrust.
    Lift UI refactored: Lift ON/OFF replaced by a preset cycle using global_WebLiftPresetPercent_Array
    (0 → preset[i] → 0 → next preset …).
    The button now displays Lift X%. Startup is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
    [hovercraft_variables.cpp, main.cpp]
2026-01-17 (untested) low battery should now turn of the motors, and make LED static
2026-01-17 high speed ADC polling
2026-01-18 updated website to have mode button, and have colored Battery-V when voltage low
2026-01-18 IR Sensor Values are measured and some data ins handed over via the que, but math does NOT work
    [hovercraft_variables.cpp, main.cpp]
2026-01-18 Step 2: correctet types
    [main.cpp]
2026-01-18 Added calibration tool for compass
2026-01-18 corrected compass settings: inverted sens and 180deg offset - this is great now! (still has prints to show it works)
2026-01-19 Shorte sample time, added angle bounds
    [main.cpp]
2026-01-19 Cleaned up Laser Parts
    [b01_top_plate_laser.dxf, holder_laser.dxf, riser_laser.dxf]
2026-01-19 added files to visualize the processes
    [diff.csv, diff.txt, results.csv]
2026-01-19 updated gitignore
    [diff.csv, diff.txt, results.csv]
2026-01-19 added motor tests
2026-01-19 Added complete documentation, removed obsolete files
    [Copie de Hovercraft.xlsx, Hovercraft_PLA_GlideRing_v1.stl, phase1_CahierDesCharges_uVerCraft_2.xlsx]
2026-01-20 fixed a small concern with memory exit / thread safety
    [hovercraft_variables.cpp, main.cpp]
2026-01-20 Commented debug Prints for testing
2026-01-20 updated yaw-stability PIDs (with website http://192.168.4.1/pid tuneable)
    [hovercraft_variables.cpp, main.cpp]
2026-01-20 last version of the old time-based sequence, // time based was: calibrate, go straight 1.6s, turn -90 0.75s, turn -180 5s, exit
2026-01-20 Fixed angle calculation. Wrapped to (-180°;180°]
    [main.cpp]
2026-01-20 autonomes with IR: 90° setpoints turn, now add pre-turning/drift to prevent excessive side-drift
    [hovercraft_variables.cpp, main.cpp]
2026-01-20 Added IMU start delay 2 sec
2026-01-31 added final presentation under "mu-verCraft-II/5_Documentation /Presentations des statut/4"
